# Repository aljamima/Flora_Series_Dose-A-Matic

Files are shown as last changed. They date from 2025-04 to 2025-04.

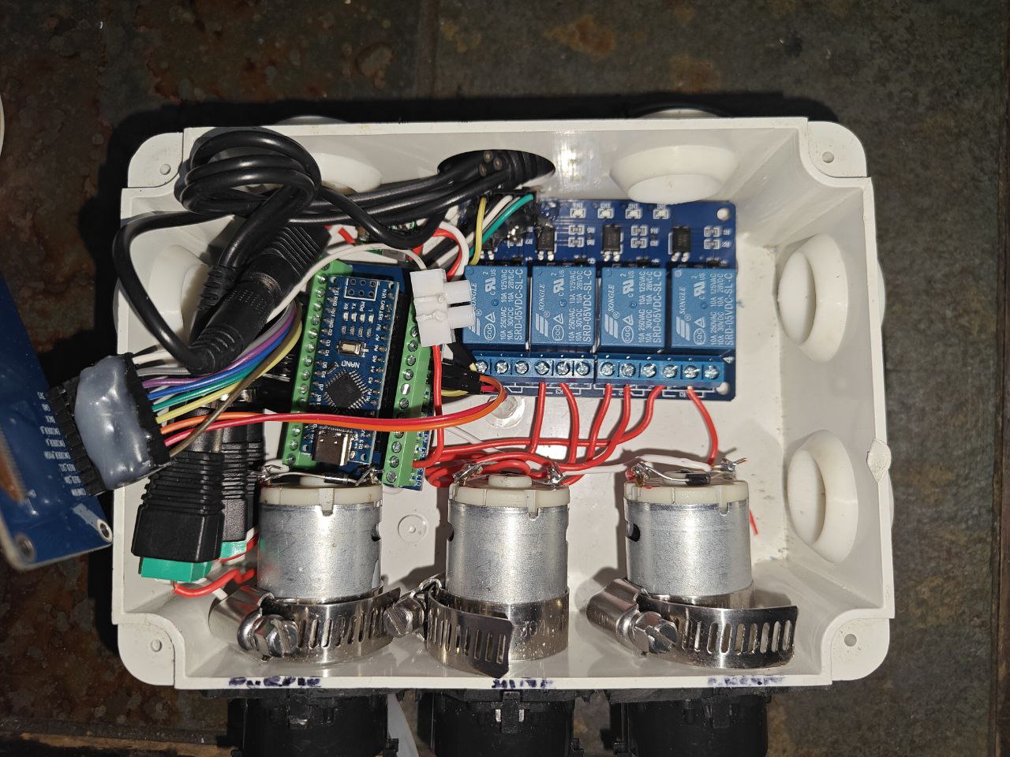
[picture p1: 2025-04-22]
images/wireNest.jpg

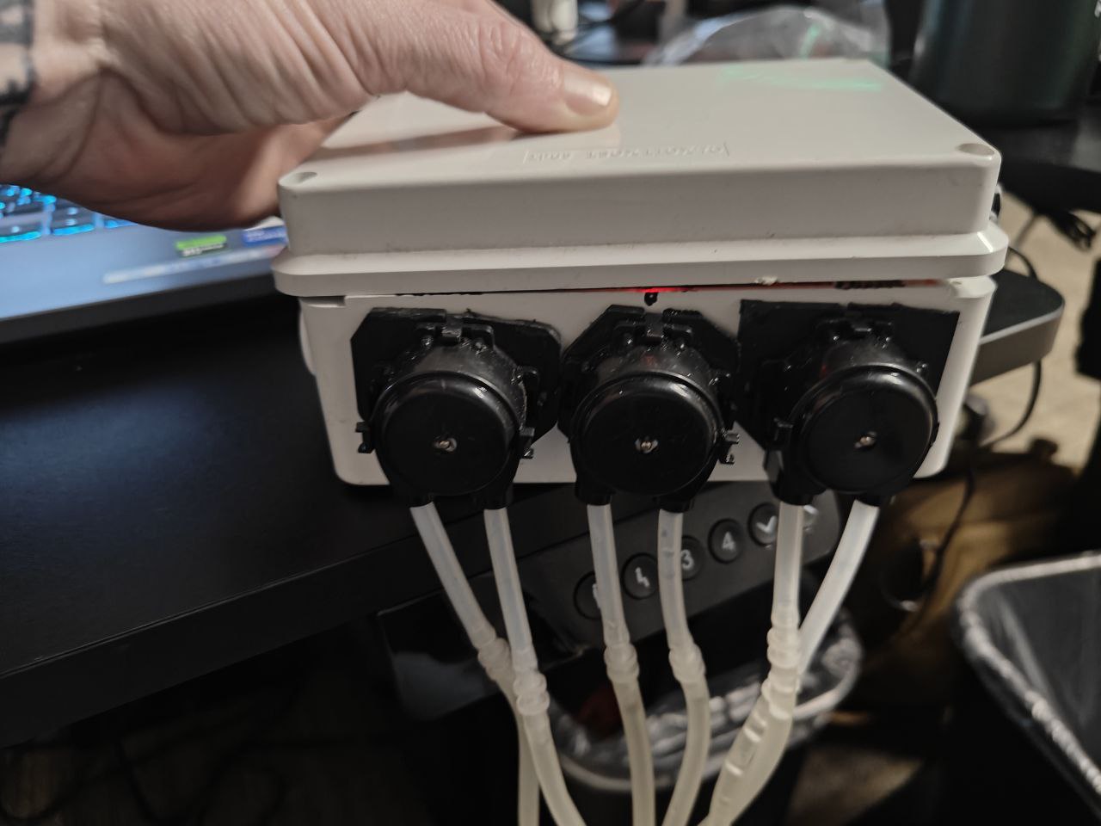
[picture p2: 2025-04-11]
images/front.jpg

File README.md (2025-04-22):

# Arduino-Based Flora_Series_Dose-A-Matic

This project is a precision nutrient dosing controller designed for hydroponic and mushroom cultivation systems. It uses an Arduino Nano to control three dosing pumps, selectable modes, and output volumes, with a clear OLED display interface and a rotary encoder for navigation. The system is designed for long-term durability and user-friendly calibration.

---

## 🧠 Features

- Selectable dosing modes: AllPurpose, Grow, Bloom
- Gallon selection: 1–100 gallons
- Individual pump calibration routine (OLED-driven)
- Relay-controlled 12V dosing pumps
- SH1106 OLED + EC11 rotary encoder UI
- Waterproof housing ready
- Calibrated per 5ml dosing resolution

---

## 🔌 Hardware Overview

### Microcontroller

- **Arduino Nano** (powered via 5V buck converter)

### Pumps

- 3x 12V DC Dosing Pumps
- Controlled via 3-channel relay module

### Relay Module

- 3-Channel mechanical relay
- IN1 = Pink
- IN2 = Purple
- IN3 = Green

### Display & Input

- SH1106 OLED (I2C)
- EC11 Rotary Encoder w/ Push Button
- Additional back/confirm buttons on module

### Power

- 12V 5A DC barrel input
- Mini360 buck converter (12V ➜ 5V)
- 5V powers Nano and relay module
- Nano’s 3.3V pin powers the OLED/Encoder module

## ⚙️ Wiring Summary

### Arduino Nano Pin Map

| Nano Pin | Function | Connected To |
| --- | --- | --- |
| D2 | Encoder A | EC11 |
| D3 | Encoder B | EC11 |
| D4 | Confirm Button | Encoder Module |
| D6 | Back Button | Encoder Module |
| D7 | Relay Green | Relay IN3 |
| D8 | Relay Purple | Relay IN2 |
| D9 | Relay Pink | Relay IN1 |
| A4 | I2C SDA | OLED Module |
| A5 | I2C SCL | OLED Module |
| 5V | Power Source | Buck Converter OUT+ |
| GND | Shared Ground  | All modules |

### Power Connections

| Source | Destination |
| --- | --- |
| 12V Barrel Jack | Buck VIN, Relay COM |
| Buck Converter OUT+ | Nano 5V, Relay VCC  |
| Buck GND | Nano GND, Relay GND |
| Nano 3.3V | OLED/Encoder VCC |

### Pump Wiring

- Relay COM terminals → 12V+
- Relay NO terminals → Pump +
- Pump – wires → PSU GND
- Flyback diodes (1N4007) across each motor (stripe to +)

---

## 🧪 Calibration Mode

- Select pump using encoder
- Adjust run-time with back button (+50ms steps)
- Press confirm to run pump
- Observe and measure volume dispensed
- Tune time until \~5ml per run

---

---


---
## 🛠 Future Ideas

- Add real-time clock (RTC) for scheduling
- Calibration Routines
- Save calibration values in EEPROM
- Replace relays with MOSFETs for faster switching
- Fully custom PCB

---

## 📸 License

This project is open source under the MIT License. Attribution appreciated, but not required.

---

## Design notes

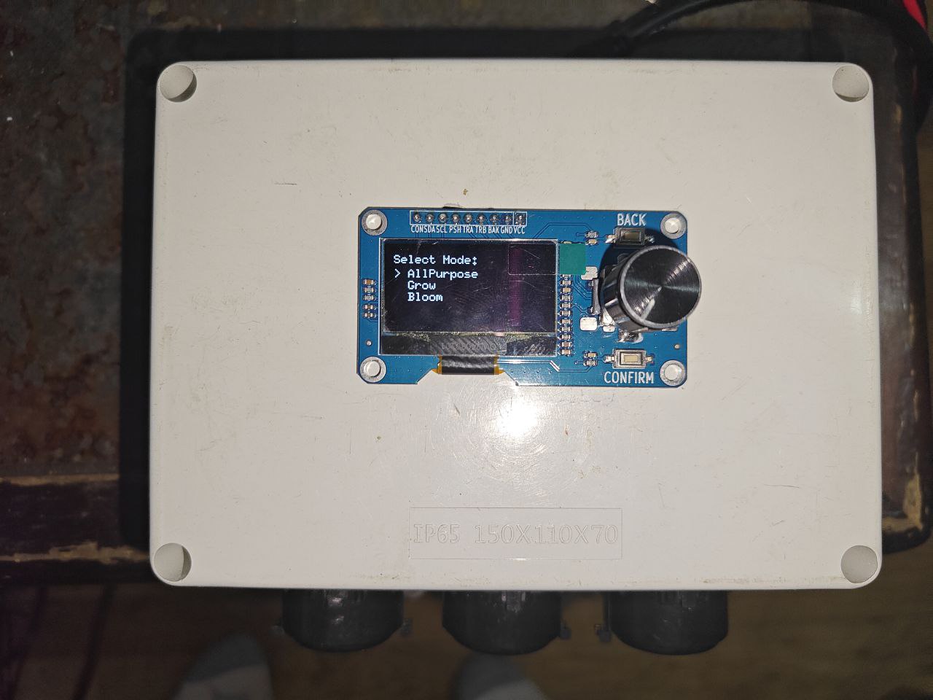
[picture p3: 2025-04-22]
images/floraDoser-topDown.jpg

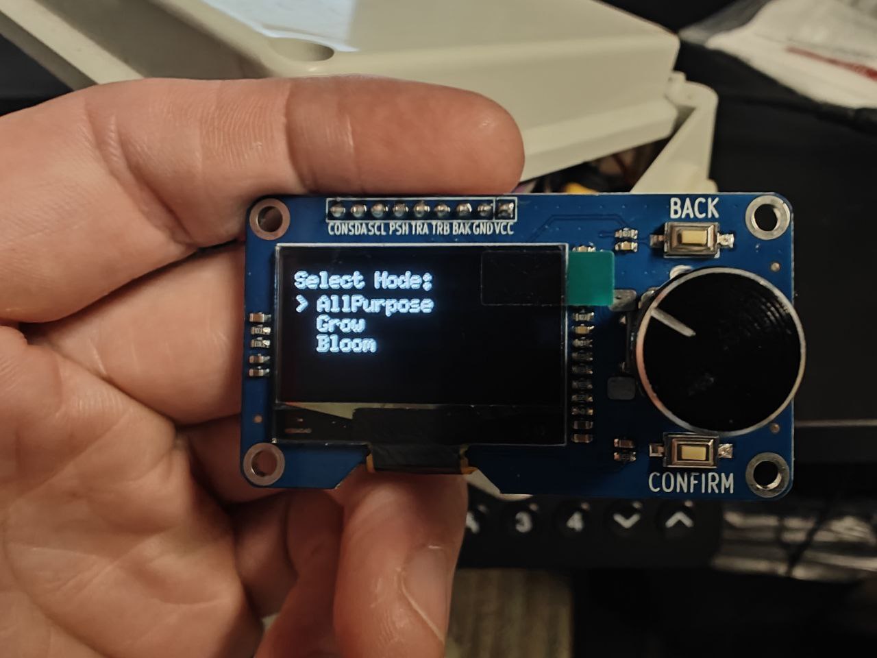
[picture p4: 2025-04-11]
images/screen.jpg

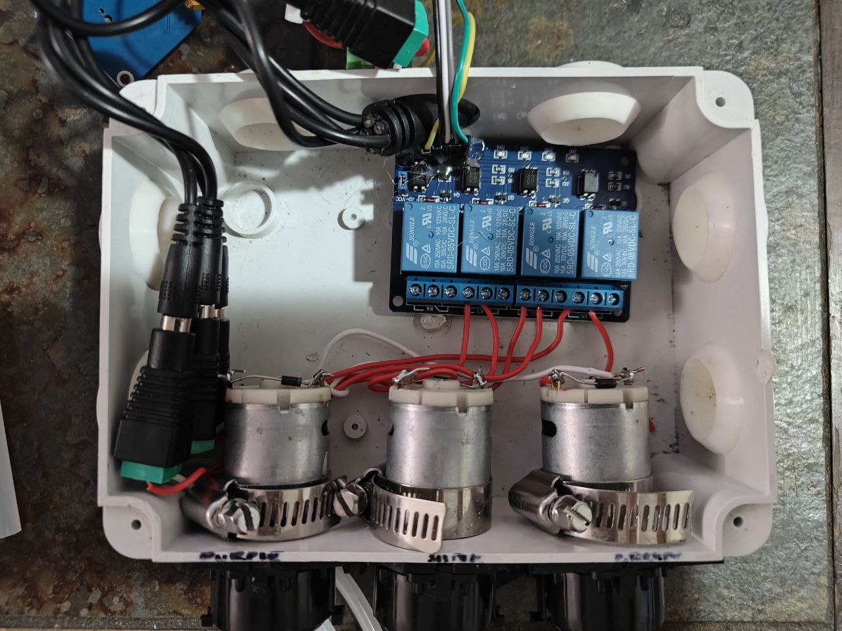
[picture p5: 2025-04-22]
images/relayWired.jpg

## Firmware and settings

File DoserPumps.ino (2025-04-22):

#include <Wire.h>
#include <U8g2lib.h>
#include <Encoder.h>

// OLED setup
U8G2_SH1106_128X64_NONAME_1_HW_I2C display(U8G2_R0, U8X8_PIN_NONE);

// Encoder
Encoder encoder(2, 3);  // CLK, DT

#define ENCODER_BTN 4
#define CONFIRM_BTN 5
#define BACK_BTN 6

#define RELAY_PINK   9
#define RELAY_PURPLE 8
#define RELAY_GREEN  7


long lastEncoderPos = 0;
int modeIndex = 0;
int gallonAmount = 1;

const int TIME_PER_5ML_MS = 2650;  // Calibrated timing per 5ml

const char* modeItems[] = {"AllPurpose", "Grow", "Bloom"};
const int modeCount = sizeof(modeItems) / sizeof(modeItems[0]);

enum ScreenState {
  MODE_SELECT,
  GALLON_SELECT,
  CONFIRM_SCREEN
};
ScreenState screenState = MODE_SELECT;

struct Dosing {
  int pink;
  int purple;
  int green;
};

Dosing dosingProfiles[] = {
  {1, 1, 1},    // AllPurpose
  {1, 2, 3},    // Grow
  {3, 2, 1}     // Bloom
};

void setup() {
  Serial.begin(115200);
  display.begin();
  display.setFont(u8g2_font_6x10_tr);

  pinMode(ENCODER_BTN, INPUT_PULLUP);
  pinMode(CONFIRM_BTN, INPUT_PULLUP);
  pinMode(BACK_BTN, INPUT_PULLUP);

  pinMode(RELAY_PINK, OUTPUT);
  pinMode(RELAY_PURPLE, OUTPUT);
  pinMode(RELAY_GREEN, OUTPUT);

  digitalWrite(RELAY_PINK, HIGH);
  digitalWrite(RELAY_PURPLE, HIGH);
  digitalWrite(RELAY_GREEN, HIGH);

  encoder.write(0);
  lastEncoderPos = 0;
  updateDisplay();
}

void loop() {
  long newPos = encoder.read() / 4;
  int delta = newPos - lastEncoderPos;

  if (delta != 0) {
    lastEncoderPos = newPos;
    if (screenState == MODE_SELECT) {
      modeIndex -= delta;
      if (modeIndex < 0) modeIndex = modeCount - 1;
      if (modeIndex >= modeCount) modeIndex = 0;
    } else if (screenState == GALLON_SELECT) {
      gallonAmount -= delta;
      if (gallonAmount < 1) gallonAmount = 100;
      if (gallonAmount > 100) gallonAmount = 1;
    }
    updateDisplay();
  }

  if (digitalRead(ENCODER_BTN) == LOW || digitalRead(CONFIRM_BTN) == LOW) {
    delay(150);
    if (screenState == MODE_SELECT) {
      screenState = GALLON_SELECT;
    } else if (screenState == GALLON_SELECT) {
      screenState = CONFIRM_SCREEN;
    } else if (screenState == CONFIRM_SCREEN) {
      runDosing(modeIndex, gallonAmount);
      screenState = MODE_SELECT;
    }
    encoder.write(0);
    lastEncoderPos = 0;
    updateDisplay();
  }

  if (digitalRead(BACK_BTN) == LOW) {
    delay(150);
    if (screenState == GALLON_SELECT) {
      screenState = MODE_SELECT;
    } else if (screenState == CONFIRM_SCREEN) {
      screenState = GALLON_SELECT;
    }
    encoder.write(0);
    lastEncoderPos = 0;
    updateDisplay();
  }
}

void runDosing(int modeIndex, int gallons) {
  Dosing d = dosingProfiles[modeIndex];

  unsigned long pinkTime   = d.pink * gallons * TIME_PER_5ML_MS;
  unsigned long purpleTime = d.purple * gallons * TIME_PER_5ML_MS;
  unsigned long greenTime  = d.green * gallons * TIME_PER_5ML_MS;

  display.firstPage();
  do {
    display.drawStr(0, 12, "Dosing Pink...");
  } while (display.nextPage());
  digitalWrite(RELAY_PINK, LOW); delay(pinkTime); digitalWrite(RELAY_PINK, HIGH);

  display.firstPage();
  do {
    display.drawStr(0, 12, "Dosing Purple...");
  } while (display.nextPage());
  digitalWrite(RELAY_PURPLE, LOW); delay(purpleTime); digitalWrite(RELAY_PURPLE, HIGH);

  display.firstPage();
  do {
    display.drawStr(0, 12, "Dosing Green...");
  } while (display.nextPage());
  digitalWrite(RELAY_GREEN, LOW); delay(greenTime); digitalWrite(RELAY_GREEN, HIGH);

  display.firstPage();
  do {
    display.drawStr(0, 12, "Dosing Complete.");
  } while (display.nextPage());
  delay(2000);
}

void updateDisplay() {
  display.firstPage();
  do {
    display.setFont(u8g2_font_6x10_tr);
    if (screenState == MODE_SELECT) {
      display.drawStr(0, 12, "Select Mode:");
      for (int i = 0; i < modeCount; i++) {
        char line[32];
        sprintf(line, "%c %s", (i == modeIndex ? '>' : ' '), modeItems[i]);
        display.drawStr(0, 24 + i * 10, line);
      }
    } else if (screenState == GALLON_SELECT) {
      display.drawStr(0, 12, "How many gallons?");
      char g[10];
      sprintf(g, "%d", gallonAmount);
      display.drawStr(30, 32, g);
    } else if (screenState == CONFIRM_SCREEN) {
      char line1[32], line2[32];
      sprintf(line1, "Mode: %s", modeItems[modeIndex]);
      sprintf(line2, "Gallons: %d", gallonAmount);
      display.drawStr(0, 12, "Confirm:");
      display.drawStr(0, 24, line1);
      display.drawStr(0, 36, line2);
      display.drawStr(0, 54, "Press confirm to run");
    }
  } while (display.nextPage());
}

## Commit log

2025-04-11 clean up
    [NutrientDoser_BOM_KiCad.csv]
2025-04-14 Calibrated pumps for 5ml increments
2025-04-22 Update DoserPumps.ino
    updated to newer version with fine tuned pump calibration at 2650ms for 5ml.
2025-04-22 removed old backups and added images
    [NutrientDoser_BOM_KiCad.csv]
2025-05-17 Added pcb fab files
    [DoserPCB.fzz]
